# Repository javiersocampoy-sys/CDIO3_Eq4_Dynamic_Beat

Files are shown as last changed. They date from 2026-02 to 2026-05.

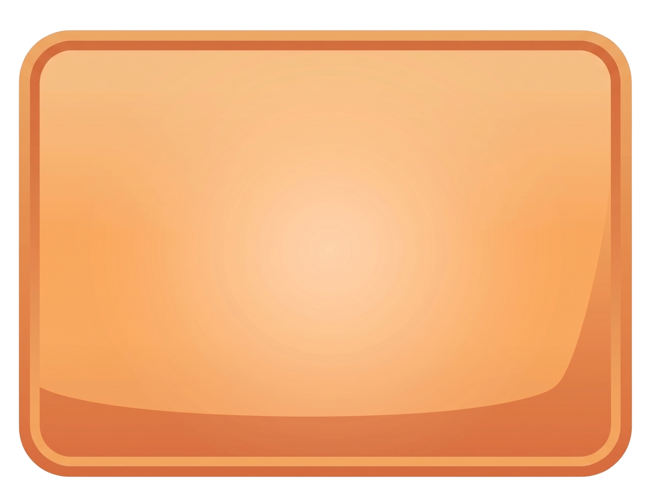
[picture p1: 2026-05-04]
03_Firmware/src/Codigo_Interfaz_Proyecto_CDIO/assets/CuadroInstrucciones.png

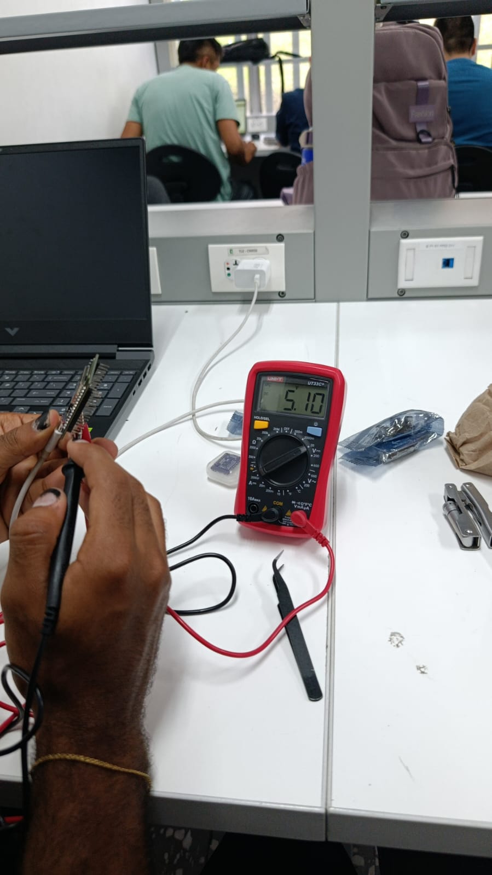
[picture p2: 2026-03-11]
04_Dossier/Evidencias/prueba alimentacion cORRIENTE Alterna.jpeg

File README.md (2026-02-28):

# CDIO3_Eq[4]_[Dynamic Beat]
En este repositorio se tendrá toda la documentación con respecto al proyecto correspondiente a la asignatura de CDIO3. 

Proyecto_CDIOIII_DYNAMIC_BEAT
DYNAMIC BEAT: Sistema interactivo para terapias de rehabilitación

DYNAMIC BEAT es una plataforma de rehabilitación basada en sistemas embebidos que digitaliza la terapia física mediante el juego. El sistema utiliza una arquitectura distribuida de sensores de ultrasonido para capturar la cinemática del paciente en tiempo real, proporcionando una métrica objetiva del progreso y transformando ejercicios repetitivos en desafíos dinámicos que aumentan la adherencia al tratamiento.

Objetivo del Proyecto
Desarrollar un prototipo didáctico de bajo costo para la Fundación Covida, enfocado en pacientes con movilidad reducida para medir y mejorar:

Precisión del Movimiento: Validación de la ejecución correcta de ejercicios mediante detección de proximidad.

Tiempo de Reacción: Medición de la velocidad de respuesta ante estímulos visuales/auditivos.

Engagement del Paciente: Gamificación de la terapia mediante una interfaz gráfica interactiva.

Seguimiento Clínico: Generación de registros de cada sesión para el análisis del terapeuta.

🛠️ Hardware y Arquitectura
El sistema opera bajo una arquitectura Hub-and-Spoke (Nodo Central y Periféricos) utilizando el protocolo ESP-NOW para una comunicación de baja latencia sin necesidad de infraestructura WiFi externa.

Lista de Componentes (BOM)

MCU Central: ESP32 WROOM 32 (Gestión de lógica y comunicación PC).

MCU Nodos (x4): XIAO ESP32C3 / Super Mini (Sensores inalámbricos remotos).

Sensores: HC-SR04 (Ultrasonido para interacción sin contacto).

Interfaz Visual: Interfaz gráfica desarrollada en Python (Pygame).

Energía: Baterías Li-ion 3.7V (2500mAh) + Regulador LM2596 + BMS para protección.

Diagrama de Bloques
[Nodos HC-SR04] --(ESP-NOW)--> [Hub ESP32] --(Serial/USB)--> [PC / Interfaz Python]

Funcionalidades Clave
1. Interacción Sin Contacto
A diferencia de los pulsadores físicos que pueden ser difíciles de accionar para pacientes con movilidad limitada, Dynamic Beat utiliza filtros de promedio móvil en los sensores ultrasonido para detectar gestos en el aire, facilitando la terapia.

2. Red Inalámbrica Propietaria
Implementa ESP-NOW, lo que permite que los objetivos de entrenamiento (nodos) se ubiquen en cualquier lugar de la sala de terapias sin cables estorbosos, manteniendo una sincronización de milisegundos con el software central.

Instalación y Uso
Firmware (ESP32/C3)

Clonar el repositorio de la lógica de sensores.

Abrir con Arduino IDE o Python.

Instalar librerías: WiFi.h, esp_now.h, NewPing (para HC-SR04).

Cargar el código de Master en el ESP32 WROOM y Slave en los nodos C3.

Software de Interfaz (PC)

Instalar Python.

Ejecutar pip install pygame pyserial.

Conectar el Hub USB y lanzar juegocdio.py.

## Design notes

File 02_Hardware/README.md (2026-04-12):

Hardware: Sistema de Rehabilitación 

Este apartado contiene toda la documentación técnica, diseños físicos y esquemáticos del hardware que compone el sistema de fisioterapia interactiva.

Descripción General

El hardware está diseñado como una red inalámbrica de sensores compuesta por 5 estaciones independientes (cajas) que funcionan bajo una arquitectura Maestro-Esclavo mediante el protocolo ESP-NOW:

Nodos Periféricos (4 estaciones): Cada caja actúa como un punto de interacción. Utilizan microcontroladores ESP32-C3 (versiones Supermini y con pantalla OLED integrada) conectados a sensores de ultrasonido HC-SR04 para detectar la proximidad de la extremidad del paciente.

Nodo Central (Maestro): Una unidad basada en ESP32 Wroom que centraliza la información de los periféricos y la transmite vía serial a un computador para la ejecución de la terapia (videojuego).

Gestión de Energía: Cada unidad es autónoma, alimentada por dos celdas de 3.7V en serie, reguladas mediante un módulo LM2596 para garantizar un voltaje estable de operación para los sensores y microcontroladores.

Contenido de la Carpeta

En esta rama del repositorio encontrarás la siguiente organización:

DATASHEETS

Contiene las hojas de especificaciones técnicas en formato PDF de los componentes críticos utilizados, asegurando que se conozcan los límites de operación de:
ESP32-C3 (Supermini & OLED version).
ESP32 Wroom.
Sensor HC-SR04.
Regulador LM2596.

MECHANICAL

Incluye los archivos de diseño para la fabricación de las 5 cajas del prototipo:

SOURCE

Contiene los archivos fuente originales y editables del diseño electrónico:

Esquemáticos de conexión.

Diseño de PCBs (en formatos compatibles con KiCad, Altium o Eagle según corresponda).

 Diagrama de Arquitectura - Dynamic Beat

A continuación, se presenta el diagrama detallado del sistema, mostrando el flujo de potencia (basado en la evidencia de cableado realizada) y la comunicación de datos:

```mermaid
graph TD
    %% Nivel 1: Energía
    subgraph Alimentacion [1. Suministro de Energía]
        BAT[2x Baterías 3.7V] -- "7.4V" --> REG[Regulador LM2596]
        REG -- "5V" --> MCU_P[ESP32-C3 Supermini]
    end

    %% Nivel 2: Acción/Sensores
    subgraph Perifericos [2. Estaciones de Interacción]
        MCU_P -- "Pines Digitales" --> HC[Sensor Ultrasonido HC-SR04]
    end

    %% Nivel 3: Comunicación Inalámbrica
    subgraph Wireless [3. Transporte de Datos]
        MCU_P -. "Protocolo ESP-NOW" .-> MASTER[Nodo Maestro: ESP32 Wroom]
    end

    %% Nivel 4: Procesamiento Final
    subgraph Interfaz [4. Salida al Videojuego]
        MASTER -- "Cable USB" --> PC[Computador: Dynamic Beat]
    end

    %% Estilos básicos
    style Alimentacion fill:#fdf,stroke:#333
    style Interfaz fill:#ddf,stroke:#333

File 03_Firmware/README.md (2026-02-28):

 Firmware Dynamic Beat 
 
Este repositorio contiene el código fuente en C++ para el sistema de control del dispositivo de fisioterapia. El firmware gestiona la lectura de sensores ultrasónicos, el control de actuadores y la interfaz de usuario, operando bajo una arquitectura de Máquina de Estados Finitos (FSM) para garantizar la precisión en las rutinas de terapia.

 Entorno de Desarrollo
Platform: PlatformIO (Recomendado) o Arduino IDE.

Framework: Arduino.

Board: esp32-c3-devkitm-1 / esp32dev (Ajustar según el módulo específico usado, como el C3 Supermini o Wroom).

Dependencias (Librerías)
Para compilar este proyecto, es necesario instalar las siguientes librerías:

NewPing (Optimización de sensores HC-SR04).

Adafruit SSD1306 (Controlador de la pantalla OLED).

Adafruit GFX (Gráficos para la interfaz).

WiFi.h (Gestión de conectividad si se usa el Wroom para telemetría).

 Pinout (Mapa de Conexiones - Borrador)
Configuración de pines sugerida (puedes ajustarla según tu config.h real):

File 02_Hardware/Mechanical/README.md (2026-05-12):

# Diseño Mecánico y Ensamblaje

Esta carpeta contiene los planos y archivos necesarios para la fabricación de la estructura física y electrónica del proyecto Dynamic Beat. 

A continuación se detalla el contenido:

* **Modelos_3D/**: Contiene los archivos 3D para imprimir las carcasas. Aquí se encuentran los diseños para las 4 cajas iguales de los nodos periféricos y el diseño específico para la caja del nodo principal (maestro).
* **Archivos_PCB/**: Contiene los documentos finales para la fabricación de las placas de circuito. Incluye los archivos técnicos Gerber (comprimidos en .zip) y los planos en PDF que muestran el diseño del circuito esquemático y el recorrido de las pistas de cobre.
* **esquematico_conexion_esp-ultrasonido**: Diagrama detallado que muestra la disposición física del sensor de ultrasonido HC-SR04 respecto a la estructura de la caja, para asegurar una detección óptima de la extremidad del paciente.

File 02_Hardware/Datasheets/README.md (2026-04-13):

Hojas de Datos (Datasheets)

En esta sección se centraliza la documentación técnica de los componentes electrónicos utilizados en el prototipo.

BOM_Sourcing.pdf: Listado de materiales (Bill of Materials) detallando proveedores, cantidades y costos aproximados para la replicación del hardware.

Documentación de Componentes: Información técnica del ESP32-C3,Placa OLED ESP32-C3 con módulo OLED, ESP32-Wroom, sensor HC-SR04 y el regulador LM2596, necesaria para entender los rangos de voltaje y operación del sistema.

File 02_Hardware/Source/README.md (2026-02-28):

Archivos Fuente Electrónicos

Aquí se encuentran los archivos originales de diseño de circuitos y esquemáticos eléctricos del sistema.

esquematico conexion fuente: Diagrama del sistema de alimentación. Detalla la conexión de las dos pilas de 3.7V en serie hacia el regulador LM2596 y la distribución de potencia a los módulos ESP32.

Diseño de Circuito: Archivos editables (KiCad/Altium/Eagle) con el ruteado de pistas y conexiones entre los nodos esclavos y el nodo maestro.

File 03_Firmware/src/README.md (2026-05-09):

#  Códigos del Sistema

Esta carpeta contiene todo el código fuente necesario para el funcionamiento de la red de sensores y la visualización de datos. La arquitectura del software está dividida en tres componentes principales: el firmware para los nodos de adquisición, el firmware del nodo central y el software de escritorio.

##  Estructura del Directorio

*   **`EMISORES`**: Contiene el firmware desarrollado para los microcontroladores ESP32 que actúan como nodos periféricos. Estos dispositivos se encargan de la lectura de los sensores (como los sensores ultrasónicos) y de transmitir la información de forma inalámbrica hacia el nodo central, utilizando el protocolo de comunicación ESP-NOW para garantizar una baja latencia.
*   **`RECEPTOR`**: Contiene el firmware para el ESP32 que actúa como nodo central o *gateway*. Este dispositivo recibe los paquetes de datos de todos los emisores de la red a través de ESP-NOW y los retransmite hacia la computadora mediante comunicación serial.
*   **`Codigo_Interfaz_Proyecto_CDIO`**: Contiene los scripts en Python que conforman la interfaz gráfica y el sistema de procesamiento. Esta aplicación lee los datos del puerto serie, los procesa y proporciona retroalimentación visual en tiempo real. 

## ⚙️ Notas de Implementación

1.  **Firmware (ESP32):** Antes de cargar los códigos, asegúrate de configurar correctamente las direcciones MAC en los archivos para que la red ESP-NOW entre los emisores y el receptor se establezca exitosamente.
2.  **Software (Python):** Verifica tener instaladas las dependencias necesarias (`pygame`, `pyserial`, etc.) antes de ejecutar el script principal de la interfaz. Puedes instalarlas ejecutando `pip install -r requirements.txt` (si aplica).

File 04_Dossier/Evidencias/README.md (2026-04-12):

Evidencias del Proyecto
Este directorio centraliza toda la documentación de respaldo, registros de validación y material gráfico recopilado durante las distintas fases de desarrollo y ensamble del sistema Dynamic Beat.

El propósito de esta carpeta es garantizar la trazabilidad de los resultados físicos y matemáticos obtenidos antes y durante la integración final.

Contenido del Directorio
La información en esta carpeta se pueden encontrar organizadas las siguientes categorías principales:

Protocolos de Pruebas: Contiene las plantillas de validación y los resultados de los puntos de prueba físicos. Esto incluye las mediciones de consumo de baterías, la verificación de los tiempos de respuesta de los sensores ultrasónicos y los reportes de estabilidad en la transmisión de datos concurrente mediante ESP-NOW.

Registros de Hardware y Control: Almacena la evidencia de la caracterización de los sistemas y el acondicionamiento de señales. Se incluyen las gráficas de respuesta en frecuencia, datos de adquisición de MATLAB/Simulink y las pruebas de velocidad del motor DC validadas con tacómetro físico.

Construcción y Ensamblaje: Archivos multimedia (fotografías y videos) que documentan el progreso físico del hardware. Abarca desde el proceso de manufactura de las PCB en la CNC y la regulación de potencia, hasta el modelado 3D y el acople del chasis electromecánico.

Sustentación y Contexto Social: Material de apoyo utilizado en las entregas formales del proyecto CDIO. Incluye los documentos y presentaciones relacionadas con el impacto del proyecto, como los soportes de la exposición sobre ingeniería electrónica, inclusión social y tecnología de asistencia.

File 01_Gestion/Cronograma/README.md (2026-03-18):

#  CDIO3_Eq4_Dynamic_Beat - Dispositivo de Fisioterapia

Este repositorio contiene el código fuente, el diseño de hardware y la documentación técnica correspondiente al desarrollo del Prototipo Mínimo Viable (PMV) de nuestro dispositivo de asistencia fisioterapéutica.

## 📑 Tabla de Contenidos
- [Tecnologías Utilizadas](#-tecnologías-utilizadas)
- [Estado del Proyecto](#-estado-del-proyecto-pmv)
- [Cronograma de Ejecución](#-cronograma-de-ejecución)

## 🛠️ Tecnologías Utilizadas
- **Microcontroladores:** Red de placas ESP32
- **Sensores:** Arreglo de sensores ultrasónicos
- **Diseño de Hardware:** Desarrollo de PCB a medida y modelado de carcasa 3D
- **Validación:** Pruebas de software e interfaz de usuario

## ⚠️ Estado del Proyecto (PMV)
Actualmente contamos con un prototipo base funcional y los siguientes entregables en curso:
- **Gestión:** Lista de materiales (BOM) consolidada y elementos adquiridos.
- **Hardware:** Diseño de circuito base completado; en fase de pruebas físicas.
- **Software:** Pruebas iniciales de software e interfaz superadas.

## 📅 Cronograma de Ejecución

A continuación, se presenta la planificación del proyecto distribuida por semanas académicas y fases de desarrollo:

```mermaid id="x8m4qp"
gantt
    title Plan de Proyecto Dynamic Beat - Semestre 2026-I
    dateFormat YYYY-MM-DD
    axisFormat %d/%m

    section Fase 1 - Diseño y Prototipado
    Lista de Materiales BOM :done, des1, 2026-02-09, 7d
    Adquisición de Componentes :done, des2, after des1, 7d
    Diseño de Circuito Electrónico :done, des3, 2026-02-16, 14d
    Pruebas de Software e Interfaz :done, des4, 2026-02-23, 14d
    Prototipo Base Terminado :milestone, 2026-03-09, 1d

    section Fase 2 - Hardware
    Validación Física Sem 6 y 7 :active, dev1, 2026-03-09, 14d
    Diseño PCB Definitiva Sem 8 :dev2, after dev1, 7d
    Modelado Carcasa 3D Sem 9 :dev3, after dev2, 7d

    section Fase 3 - Integración
    Ensamble y Pruebas Sem 10 :int1, after dev3, 7d
    Validación Operativa Sem 11 :int2, after int1, 7d

    section Fase 4 - Implementación
    Evaluación con Cliente Sem 12 :crit, usr1, after int2, 21d
    Ajustes de Mejora Continua :doc1, after usr1, 7d
    Sustentación Final Sem 15 :milestone, 2026-05-11, 1d
```

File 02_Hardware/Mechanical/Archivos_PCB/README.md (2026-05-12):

# Archivos de la PCB

En esta carpeta se guardan todos los documentos finales para la fabricación y revisión de las placas de circuito del proyecto Dynamic Beat. Aquí encontrarás:

- **Archivos Gerber (.zip):** Los archivos técnicos comprimidos listos para mandar a fabricar las placas (PCB) mediante CNC o con un fabricante.
- **Planos en PDF:** Documentos de fácil lectura que muestran el diseño del circuito (esquemático) y el diseño físico con las pistas (ruteo) de los nodos.

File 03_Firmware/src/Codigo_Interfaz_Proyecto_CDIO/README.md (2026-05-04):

Esta carpeta contiene el **código principal del sistema interactivo**, desarrollado en Python utilizando **Pygame**, el cual se comunica con un **ESP32** mediante puerto serial.
El juego está diseñado para ser utilizado en sesiones de fisioterapia, donde el usuario interactúa con sensores físicos que envían señales al sistema.

### 🔹 main.py

Contiene:

* Lógica completa del juego
* Lectura del puerto serial (ESP32)
* Renderizado de la interfaz gráfica
* Control de puntuación, animaciones y flujo del juego

### 🔹 assets/

Contiene todos los recursos gráficos utilizados:

* Imágenes (botones, fondos, flechas, personajes)
* Tipografías personalizadas (.ttf)

⚠️ IMPORTANTE:
El código actualmente usa una **ruta absoluta**, por lo que debe modificarse para que funcione en otros equipos.

Ejemplo actual:

```python
ruta_imagenes = "C:\\Users\\Javier S Ocampo\\Documents\\Juego CDIO\\Imagenes"
```

Se recomienda cambiarlo a ruta relativa:

```python
ruta_imagenes = os.path.join(os.path.dirname(__file__), "assets")
```

---

##  Requisitos para ejecutar el sistema

Antes de ejecutar el código, asegúrese de tener instalado:

* Python 3.x
* Librerías necesarias:

```bash
pip install pygame pyserial
```

---

##  Configuración del puerto serial (MUY IMPORTANTE)

El sistema se comunica con un **ESP32**, por lo tanto es necesario configurar correctamente el puerto serial.

###  Línea a modificar en el código:

```python
puerto_serial = serial.Serial('COM4', 115200, timeout=0.01)
```

###  ¿Qué debe hacer el usuario?

* En Windows:

  1. Abrir el **Administrador de dispositivos**
  2. Buscar el ESP32 en "Puertos (COM y LPT)"
  3. Identificar el puerto asignado (ej: COM3, COM5, etc.)
  4. Reemplazar `'COM4'` por el puerto correspondiente

* En Linux/Mac:
  Puede ser algo como:

  ```bash
  /dev/ttyUSB0
  /dev/ttyACM0
  ```

---

##  Cómo ejecutar el juego

1. Conectar el ESP32 al computador
2. Verificar el puerto serial
3. Ajustar la ruta de imágenes (si es necesario)
4. Ejecutar:

```bash
python main.py
```

---

##  Funcionamiento del sistema

El ESP32 envía datos por serial en el siguiente formato:

```
SensorX -> Letra
```

Ejemplo:

```
Sensor1 -> B
```

El sistema interpreta estas letras como direcciones:

| Letra | Acción |
| ----- | --- |
| B | Arriba (↑) |
| A | Abajo (↓) |
| C | Izquierda (←) |
| D | Derecha (→) |

---

## ⚠️ Consideraciones importantes

* Si el juego no responde:

  * Verificar conexión serial
  * Verificar puerto correcto
* Si no cargan imágenes:

  * Revisar rutas en `assets`
* Si hay errores:

  * Revisar instalación de librerías

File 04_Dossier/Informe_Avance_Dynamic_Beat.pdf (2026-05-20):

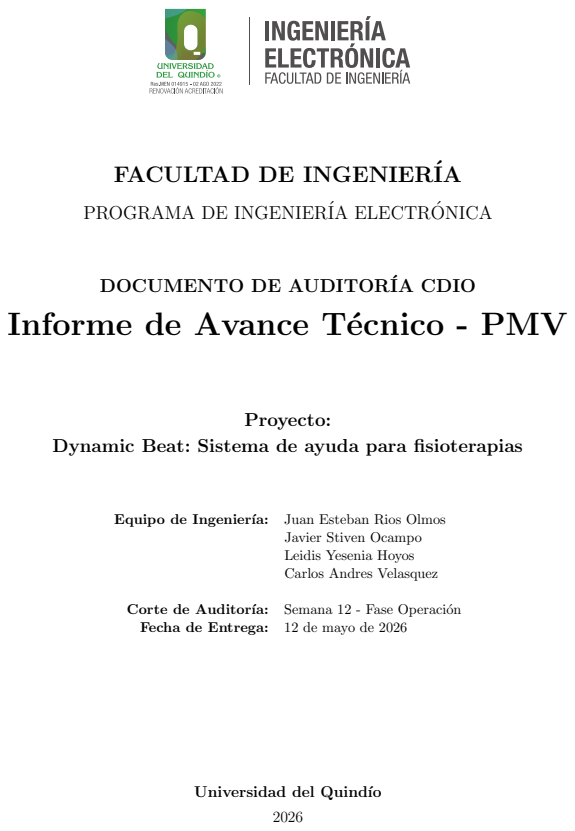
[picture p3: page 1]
Proyecto:; Equipo de Ingeniería:; Juan Esteban Rios Olmos; Corte de Auditoría:; Semana 12 - Fase Operación; Fecha de Entrega:; 12 de mayo de 2026

FACULTAD DE INGENIERÍA

PROGRAMA DE INGENIERÍA ELECTRONICA ´

DOCUMENTO DE AUDITORÍA CDIO

Informe de Avance Técnico - PMV

Dynamic Beat: Sistema de ayuda para fisioterapias

Javier Stiven Ocampo
Leidis Yesenia Hoyos
Carlos Andres Velasquez

Universidad del Quindío

## Índice

1. Resumen Ejecutivo | 2
2. Estado de Cumplimiento ON-Ramp | 2
3. Resultados de Verificación y Validación (V&V) | 2
4. Desempeño Operativo (MAHD + Kanban) | 3
5. Auditoría Financiera (CVU) | 3
6. Próximos Pasos (Roadmap S12 a S14) | 3
7. Anexos y Evidencia Técnica | 5

## 1. Resumen Ejecutivo

El proyecto Dynamic Beat se reporta actualmente en estado VERDE-AMARILLO. El logro principal (IPAC) de este ciclo fue la consolidación de la arquitectura de hardware, utilizando 1 ESP32-WROOM como receptor central de la información enviada por 4 módulos ESP32-C3 SuperMini mediante el protocolo ESP-NOW, integrándose exitosamente con la interfaz gráfica en Python. Se alcanzó la validación eléctrica completa, operando de manera autónoma con 2 baterías LiPo y un regulador LM2596 que entrega una salida estable de 5.06 V bajo carga. El estado de precaución se debe netamente a desafíos mecánicos superados recientemente durante el ensamble de las carcasas, garantizando un PMV auditable.

## 2. Estado de Cumplimiento ON-Ramp

A continuación, se contrasta la promesa técnica del diseño inicial frente a la realidad del prototipo funcional en la Semana 12.

Tabla 1: Trazabilidad de Requisitos: Matriz ON-Ramp vs. PMV Actual

ID | Requisito Original (Promesa) | Estado | Observaciones / Desviaciones
RF-001 | Entrada de 8.7V (±5 %). Salida 5V
(±0.3V).

Logrado Operación exitosa a 5.06 V constantes vía módulo Step-Down LM2596 alimentado por dos baterías LiPo.

RF-004 | Visualización | de | imágenes | sin
distorsión | (Resolución | mínima
| 800x700px).
Logrado | Interfaz de juego implementada en
Pygame a 800x700px.

RNF-001 Operar con variaciones de voltaje sin fallos (±10 %).

Logrado Sistema estable operando a baterías con autonomía de 3 a 5 horas continuas sin reinicios de los microcontroladores.

RNF-003 | Tiempo de respuesta en la selección
| menor a 1s.
Logrado | Antirrebote por software imple-
mentado exitosamente tras validar el uso de sensores HC-SR04 para detección de extremidades.

RNF-005 Protección IP40 contra polvo y humedad (± 1 nivel).

Logrado Las carcasas encajan con las tapas y son celladas con tornillos, protegiendo efectivamente las PCBs del polvo, garantizando protección de nivel básico.

## 3. Resultados de Verificación y Validación (V&V)

El proceso de V&V se ha ejecutado conforme al protocolo establecido en el laboratorio. Las 9 pruebas documentadas en el registro oficial culminaron en estado PASS, incluyendo validaciones críticas de comunicación y detección de extremidades en los nodos.
Durante el desarrollo de la interfaz gráfica y los sensores (reemplazando los botones físicos originales por ultrasonido HC-SR04 para mejorar la accesibilidad), se detectaron y solucionaron dos fallos lógicos. El primero fue un rebote de señal donde una sola interacción generaba múltiples aciertos y fallos simultáneos, lo cual se mitigó programando un cooldown (antirrebote) en el código. El segundo fallo fue un error de mapeo en la transmisión serial que causaba que la interfaz solo detectara el nodo amarillo e ignorara el resto de colores, lo cual fue solucionado sincronizando la lectura de línea completa para extraer únicamente el identificador correcto de cada ESP Mini.

Tabla 2: Consolidado de Pruebas Técnicas Ejecutadas (Muestra representativa)

ID Prueba | Parámetro Evaluado | Resultado | Dato Registrado (Eviden-
cia)
TEST-HW-01 | Regulación | de | voltaje
(LM2596).

PASS Salida estable 4.9 V - 5.1 V bajo carga de 10Ω.

TEST-PWR-02 | Consumo y batería. | PASS | Autonomía operativa continua
de 3 a 5 horas.
TEST-COM-03 | Transmisión Serial PC-ESP. | PASS | Datos íntegros tras lag inicial
de emparejamiento.
TEST-SEN-01 | Detección ultrasónica. | PASS | Detección de extremidades con
margen de error mínimo.

## 4. Desempeño Operativo (MAHD + Kanban)

### 4.1. Gestión de Flujo y Cuellos de Botella

La fase de manufactura física representó el mayor cuello de botella. Se identificaron tres percances mecánicos: 1) Los cables de los portapilas comerciales sufrieron fatiga mecánica debido al peso de las baterías, rompiéndose repetidamente, lo que obligó a reemplazarlos por cableado de mayor calibre. 2) La primera iteración de la PCB fresada (TEST-HW-03) falló por la omisión del efecto espejo en los footprints, retrasando el ensamble por 2 días hasta la manufactura de la placa corregida. 3) Se requirió un re-diseño operativo en la carcasa para incluir un switch externo, evitando destapar los módulos para el encendido.

### 4.2. Estado del Repositorio (GitHub)

La trazabilidad del proyecto refleja un alto nivel de actividad. A la fecha, se han registrado

### 89 commits en la red del repositorio. El tablero Kanban evidencia 13 tareas finalizadas

(Done) y 5 tareas activas (In Progress) centradas principalmente en validación (Validation) y desarrollo (Development).

## 5. Auditoría Financiera (CVU)

El Costo Variable Unitario (CVU) ejecutado se basa en el Bill of Materials (BOM) actualizado. Dado que no se fijó un presupuesto inicial rígido, se reporta la liquidación neta actual para la trazabilidad de los activos. (El desglose detallado de los componentes se presenta al final de este informe en la Tabla 3).

## 6. Próximos Pasos (Roadmap S12 a S14)

El Backlog para el cierre técnico del hardware queda sujeto a las iteraciones y modificaciones que la dirección académica (profesor) exija tras esta auditoría. Las tareas preliminares incluyen la estabilización final de la interfaz de juego y la actualización de los repositorios en GitHub con las versiones As-Built de los esquemáticos y la documentación.

Tabla 3: Análisis de Costos de Hardware (BOM Real Ejecutado)

Componente | Cant. | V. Unitario | Costo Total
ESP32 C3 SuperMini | 2 | $ 9,348.00 | $ 18,696.00
Placa OLED ESP32-C3 | 2 | $ 10,814.44 | $ 21,628.88
ESP32 Wroom 32 | 1 | $ 14,481.95 | $ 14,481.95
Sensor HC-SR04 | 4 | $ 12,000.00 | $ 48,000.00
Batería LiPo 3.7V | 8 | $ 12,000.00 | $ 96,000.00
Portapilas para baterías LiPo | 4 | $ 4,000.00 | $ 16,000.00
Cargador de baterías | 1 | $ 14,000.00 | $ 14,000.00
Regulador LM2596 | 1 | $ 14,000.00 | $ 14,000.00
Cajas | 5 | $ 7,400.00 | $ 37,000.00
PCB impresa | 2 | $ 2,400.00 | $ 4,800.00
Borneras de alimentación | 4 | $ 800.00 | $ 3,200.00
Regletas de pines | 3 | $ 2,000.00 | $ 6,000.00
Cable USB-C (Microcontrolador Maestro) | 1 | $ 20,000.00 | $ 20,000.00
LED RGB indicador | 1 | $ 1,000.00 | $ 1,000.00
Resistencias de 100 y 39 Ohms | 3 | $ 200.00 | $ 600.00
Soldadura (Estaño 1 metro) | 1 | $ 2,000.00 | $ 2,000.00
Switch externo | 4 | $ 800.00 | $ 3,200.00
Decoración | 1 | $ 2,000.00 | $ 2,000.00
TOTALES | 47 | $ 129,244.39 | $ 322,606.83

## 7. Anexos y Evidencia Técnica

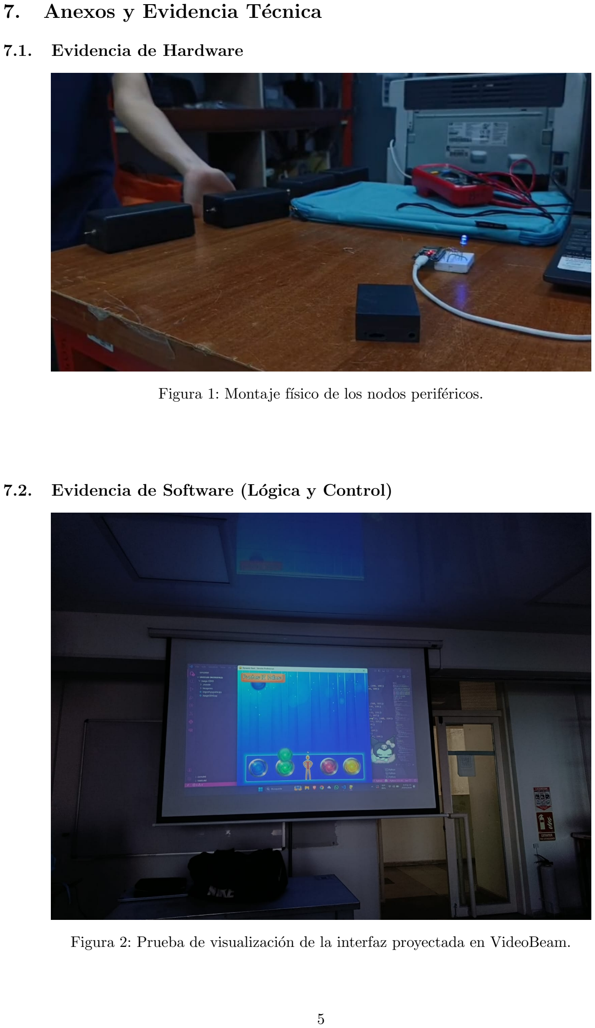
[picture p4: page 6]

### 7.1. Evidencia de Hardware

Figura 1: Montaje físico de los nodos periféricos.

### 7.2. Evidencia de Software (Lógica y Control)

Figura 2: Prueba de visualización de la interfaz proyectada en VideoBeam.

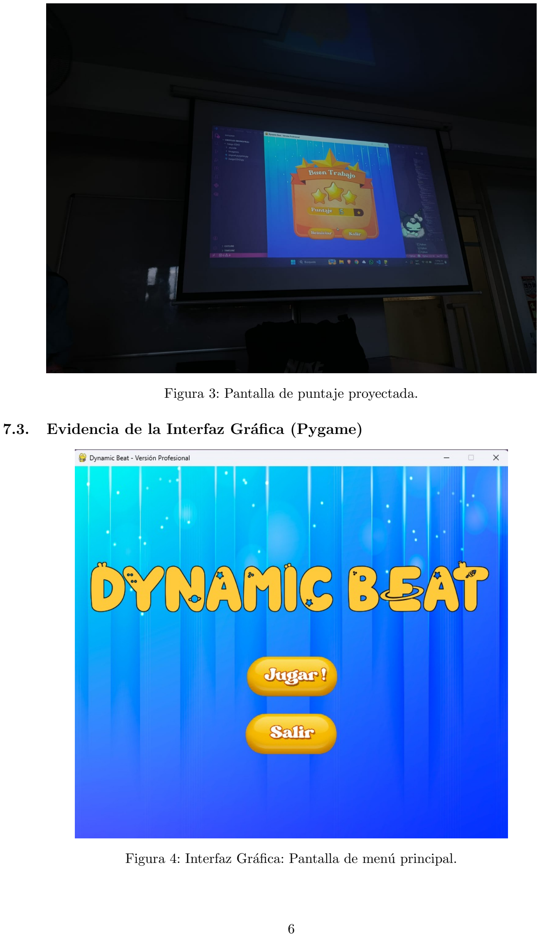
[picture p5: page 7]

Figura 3: Pantalla de puntaje proyectada.

### 7.3. Evidencia de la Interfaz Gráfica (Pygame)

Figura 4: Interfaz Gráfica: Pantalla de menú principal.

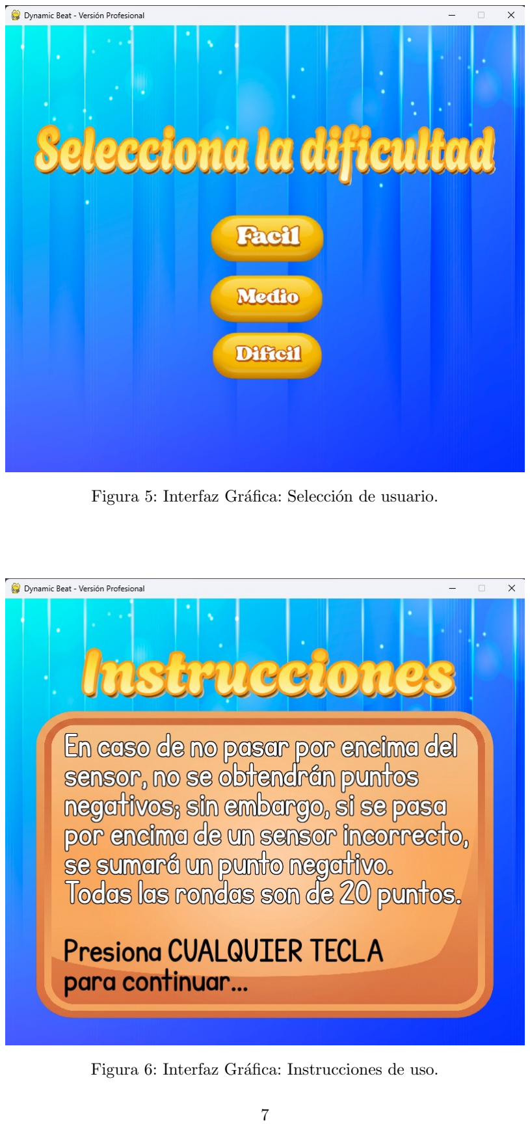
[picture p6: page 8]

Figura 5: Interfaz Gráfica: Selección de usuario.

Figura 6: Interfaz Gráfica: Instrucciones de uso.

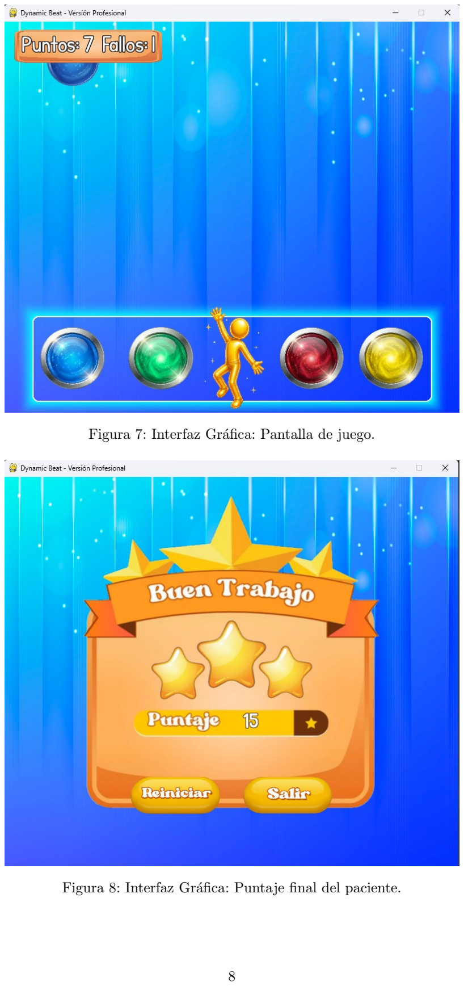
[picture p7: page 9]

Figura 7: Interfaz Gráfica: Pantalla de juego.

Figura 8: Interfaz Gráfica: Puntaje final del paciente.

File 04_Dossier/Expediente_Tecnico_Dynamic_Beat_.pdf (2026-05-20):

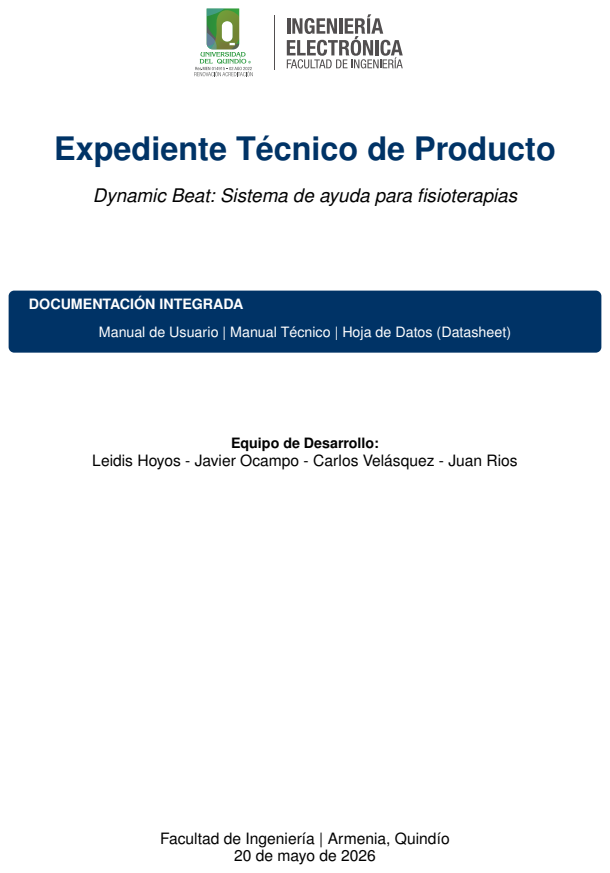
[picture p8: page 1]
DOCUMENTACIÓN INTEGRADA

Expediente Técnico de Producto

Dynamic Beat: Sistema de ayuda para fisioterapias

Manual de Usuario | Manual Técnico | Hoja de Datos (Datasheet)

Equipo de Desarrollo:

Leidis Hoyos - Javier Ocampo - Carlos Velásquez - Juan Rios

Facultad de Ingeniería | Armenia, Quindío

20 de mayo de 2026

Proyecto CDIO III: DYNAMIC BEAT | Rev. 1.2 - Mayo 2026

## Índice

1. HOJA DE DATOS (DATASHEET) | 2
2. MANUAL DE USUARIO | 6
3. MANUAL TÉCNICO | 11
Universidad del Quindío - Ingeniería Electrónica | 1

## 1 HOJA DE DATOS (DATASHEET)

### 1.1 Descripción General

DYNAMIC BEAT es un sistema inalámbrico de asistencia para rehabilitación motriz compuesto por un nodo maestro (ESP32-WROOM32) y cuatro nodos periféricos (2 ESP32-C3 SuperMini y 2 ESP32-C3 SuperMini OLED). El sistema utiliza sensores ultrasónicos (ver Figura 4) para la detección de presencia sin contacto, facilitando terapias de bajo impacto físico. La comunicación se realiza mediante el protocolo ESP-NOW, garantizando latencias inferiores a 400ms.

### 1.2 Especificaciones Técnicas

Parámetro | Descripción | Valor/Unidad
Voltaje de Alimentación Nominal | Entrada DC regulada (LiPo 2S) | 7,4V − 8,4V
Consumo Nominal | Corriente promedio del sistema | 300mA
Autonomía de Batería | Tiempo de operación continua | 3,0 − 5,0 h
Rango de Detección | Distancia útil del sensor HC-SR04 | 3,0 − 15,0 cm
Precisión de Medición | Margen de error en distancia | ±3,0 mm
Ángulo de Detección | Cono de medición efectivo | < 15◦
Latencia de Sistema | Tiempo de respuesta End-to-End | 0,34 s
Frecuencia de Operación | Banda ISM Inalámbrica | 2,4 GHz

Tabla 1: Especificaciones operativas nominales del sistema.

### 1.3 Valores Máximos Absolutos

Nota: Operar el dispositivo bajo estas condiciones por periodos prolongados puede afectar la fiabilidad del equipo o causar daño permanente a los microcontroladores.

Parámetro | Condición | Límite Máximo
Voltaje de Entrada (Etapa Regulación) | Directo a la placa de distribución | 8,6V DC
Voltaje Máximo Transitorio (ESP32) | Picos de corta duración en la ló-gica | 5,6V DC
Temperatura de Operación | Ambiente de trabajo (Carcasas PLA) | ◦C a 45◦C 0
Temperatura de Almacenamiento | Equipo apagado y guardado | −10◦C a 50◦C

Tabla 2: Límites máximos de tolerancia de hardware.

### 1.4 Características Mecánicas

Los nodos están protegidos por carcasas fabricadas mediante manufactura aditiva en material PLA, diseñadas para soportar el impacto moderado del uso fisioterapéutico.

### 1.5 Diagramas de Conexiones y Hardware

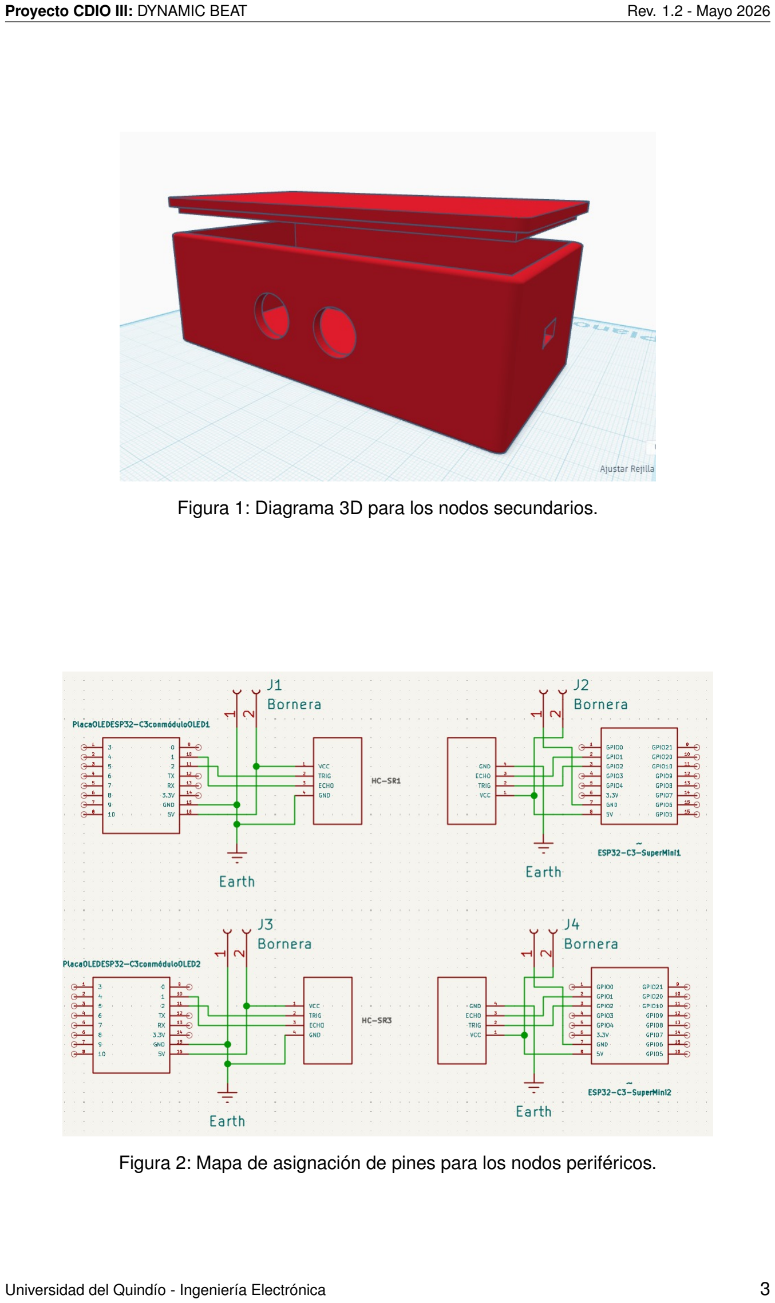
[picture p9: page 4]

Figura 1: Diagrama 3D para los nodos secundarios.

Figura 2: Mapa de asignación de pines para los nodos periféricos.

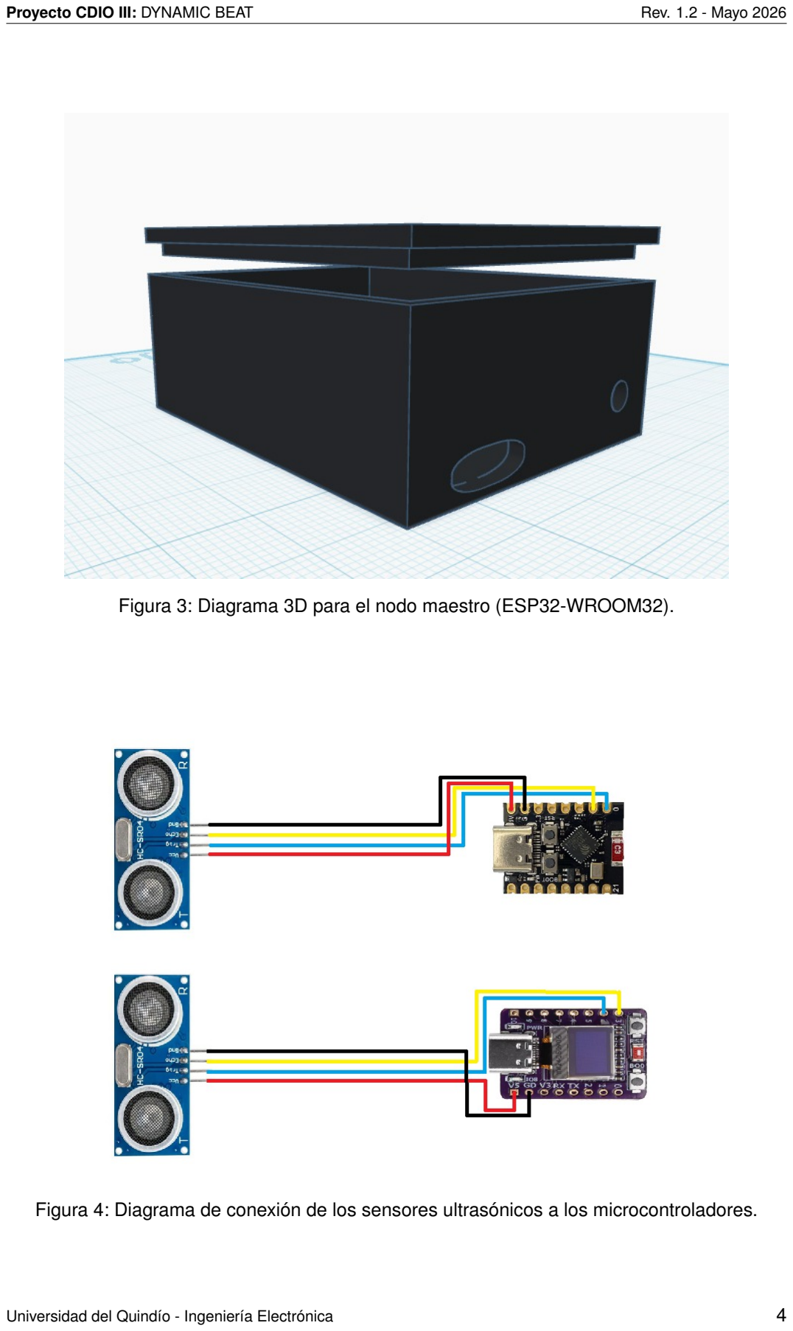
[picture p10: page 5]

Figura 3: Diagrama 3D para el nodo maestro (ESP32-WROOM32).

Figura 4: Diagrama de conexión de los sensores ultrasónicos a los microcontroladores.

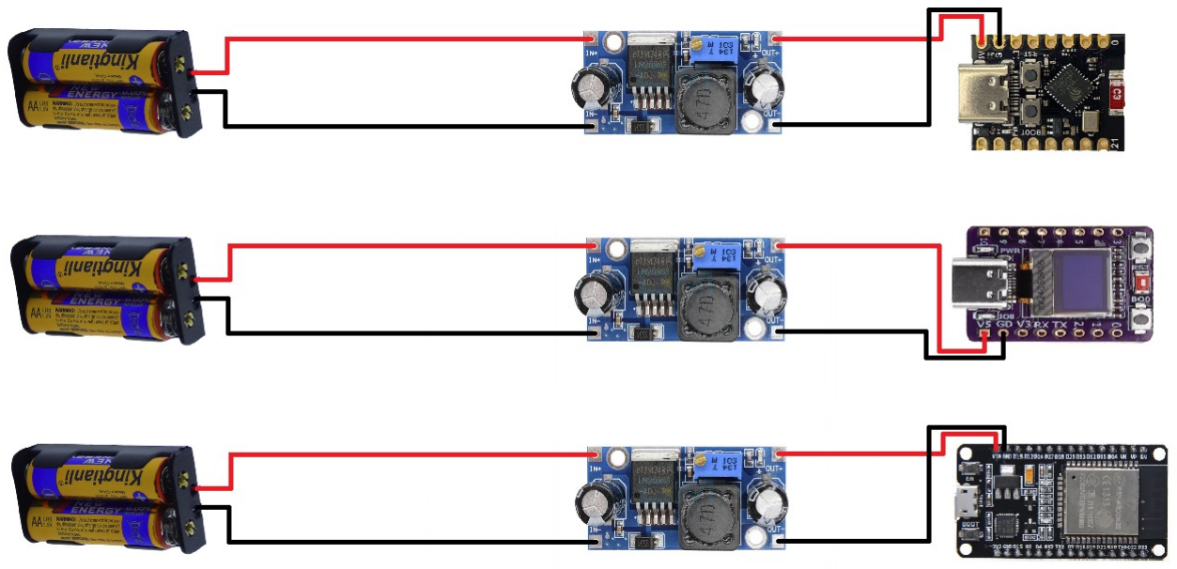
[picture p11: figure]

Figura 5: Diagrama de conexión de las baterías, reguladores y microcontroladores.

## 2 MANUAL DE USUARIO

. ADVERTENCIA DE SEGURIDAD

No exponga las carcasas a humedad directa. En caso de detectar olor a quemado o sobrecalentamiento, mueva todos los interruptores a la posición OFF de inmediato.

### 2.1 Contenido del Paquete

El sistema DYNAMIC BEAT incluye los siguientes elementos. Por favor, verifique que todos estén presentes antes de iniciar:

1x Nodo principal: Carcasa pequeña con LED indicador y entrada USB tipo C.

4x Nodos sensoriales: Carcasas con identificadores de colores.

1x Cable USB-C: Para alimentación y comunicación del nodo principal.

1x Cargador de baterías: Para la recarga de las baterías 18650 de los nodos.

1x Software: Aplicación de interfaz gráfica Dynamic Beat.

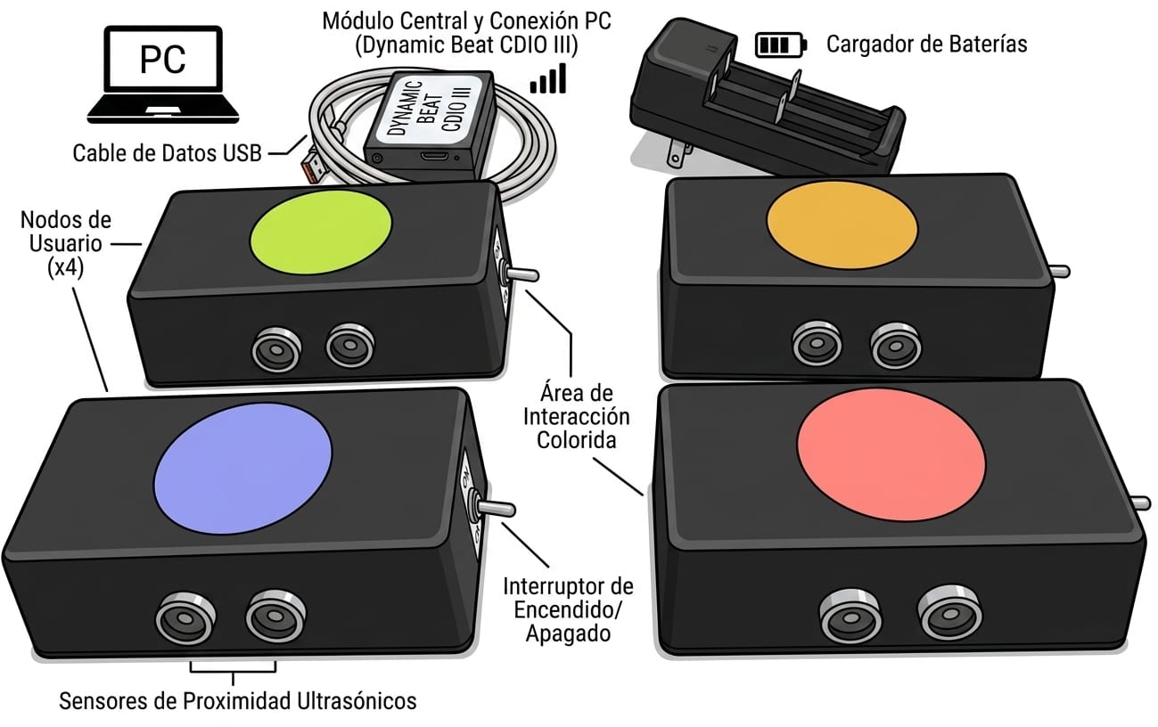
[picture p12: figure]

Figura 6: Materiales entregados y disposición de los componentes del sistema.

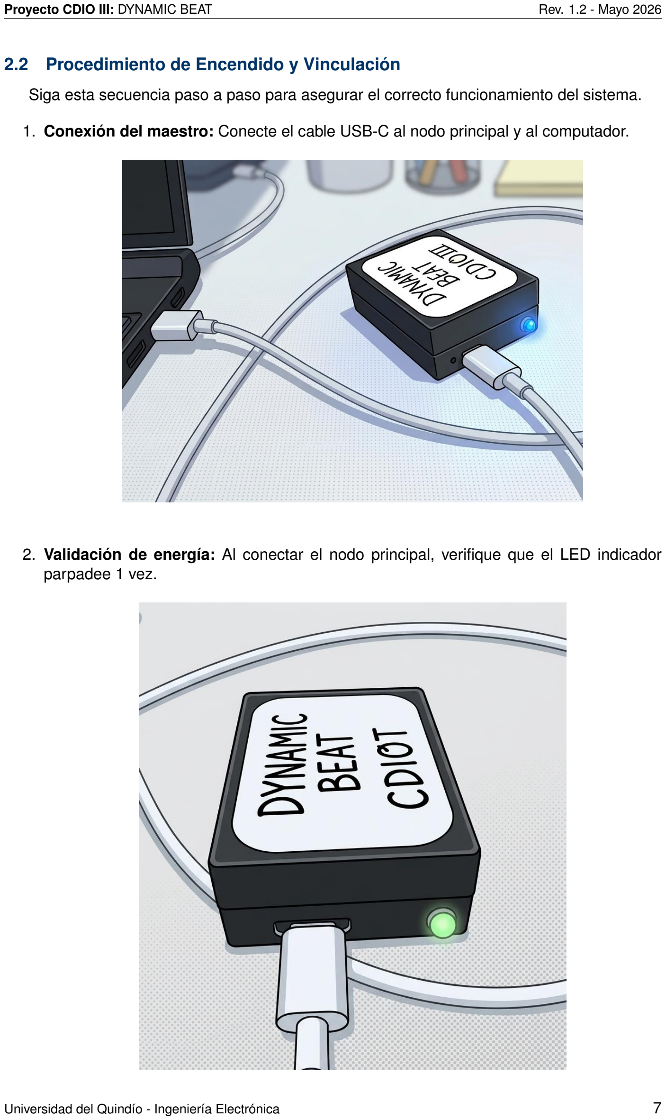
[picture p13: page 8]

### 2.2 Procedimiento de Encendido y Vinculación

Siga esta secuencia paso a paso para asegurar el correcto funcionamiento del sistema.

1. Conexión del maestro: Conecte el cable USB-C al nodo principal y al computador.
2. Validación de energía: Al conectar el nodo principal, verifique que el LED indicador parpadee 1 vez.

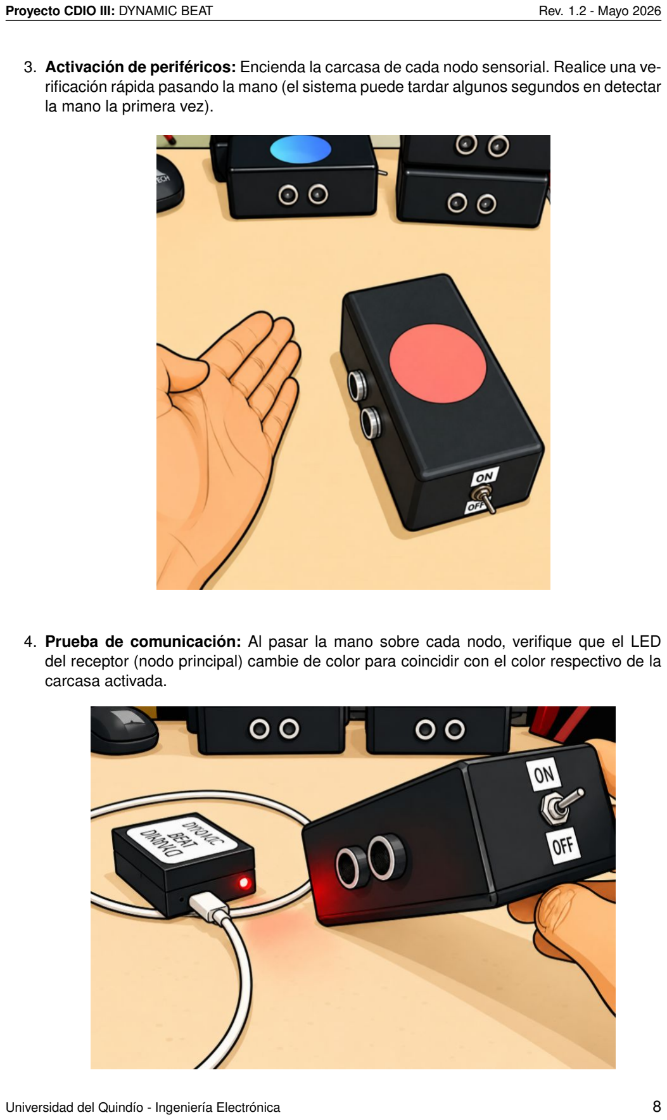
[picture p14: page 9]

3. Activación de periféricos: Encienda la carcasa de cada nodo sensorial. Realice una verificación rápida pasando la mano (el sistema puede tardar algunos segundos en detectar la mano la primera vez).
4. Prueba de comunicación: Al pasar la mano sobre cada nodo, verifique que el LED del receptor (nodo principal) cambie de color para coincidir con el color respectivo de la carcasa activada.

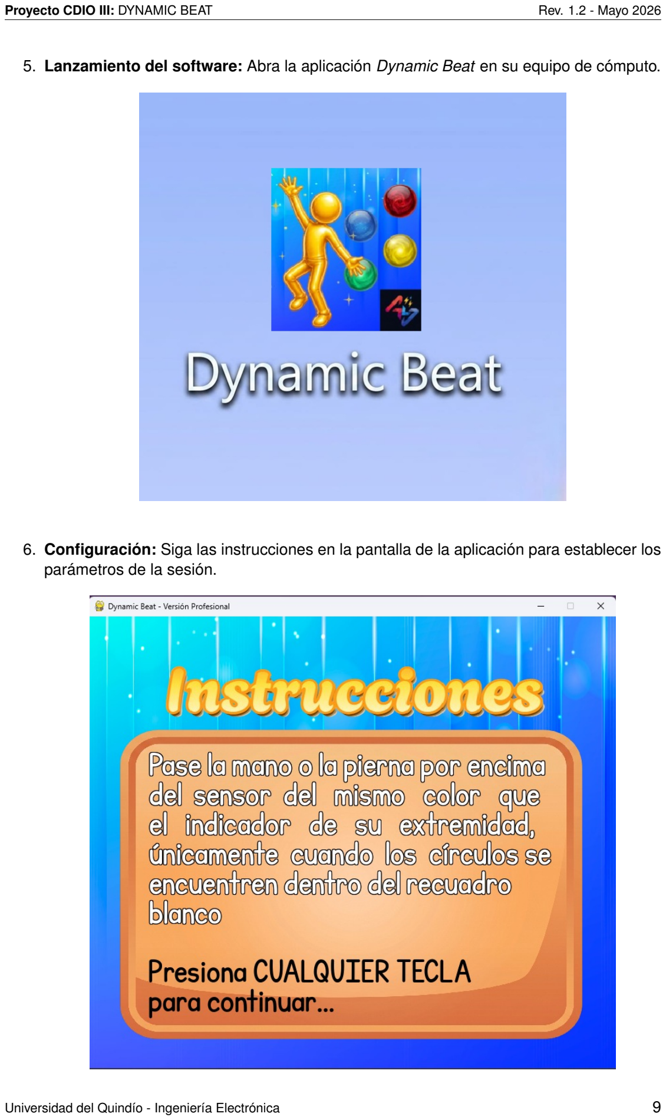
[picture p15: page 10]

5. Lanzamiento del software: Abra la aplicación Dynamic Beat en su equipo de cómputo.
6. Configuración: Siga las instrucciones en la pantalla de la aplicación para establecer los parámetros de la sesión.

7. ¡Iniciar prueba!: Una vez configurado todo en el software, inicie la rutina e interactúe con los nodos.

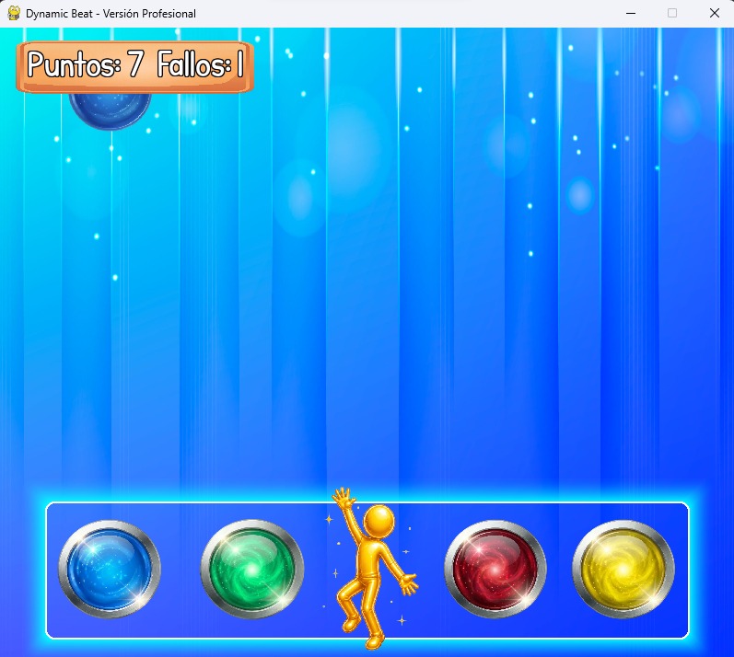
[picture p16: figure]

### 2.3 Tabla de Diagnóstico y Solución de Problemas

Si el sistema presenta alguna falla en su funcionamiento, localice el síntoma en la siguiente tabla y siga las instrucciones recomendadas antes de solicitar asistencia técnica.

Síntoma / Problema | Posible Causa | Solución Sugerida
El nodo sensorial no en-ciende o la luz indicadora se apaga de forma inter-mitente. | Las baterías 18650 están to-talmente descargadas o se movieron de su posición den-tro de la carcasa. | Retire las baterías y verifique que estén bien colocadas. Si continúa apagado, use el cargador incluido para recargarlas.
La interfaz gráfica no re-gistra los puntos al inter-actuar con un nodo acti-vo. | Presencia de obstáculos cer-canos o suciedad acumulada en la rejilla frontal del sensor. | Asegúrese de pasar la mano estrictamen-te dentro del rango de detección de 15 cm. Limpie suavemente la malla del sen-sor ultrasónico y despeje el área de juego.
La aplicación se queda congelada, no recibe da-tos o la respuesta es muy lenta. | Fallo temporal en la comuni-cación entre el nodo princi-pal y el sistema operativo del computador. | Desconecte el cable USB-C del nodo prin-cipal, espere 5 segundos y vuelva a co-nectarlo. Si el problema persiste, cambie el cable a otro puerto USB del compu-tador y reinicie la aplicación.

ò CONSEJO TÉCNICO DE RESPALDO

Alimentación Directa por Cable: Recuerde que cada una de las 4 carcasas (nodos sensoriales) incluye su propio puerto USB-C independiente. Si las baterías 18650 se descargan en medio de una actividad y no tiene tiempo de recargarlas, puede conectar un cable de alimentación directo a la caja para seguir utilizando el sistema sin interrupciones.

## 3 MANUAL TÉCNICO

### 3.1 Teoría de Operación

El sistema opera bajo una arquitectura en estrella sobre el protocolo ESP-NOW. El nodo maestro actúa como puente serial entre la red inalámbrica y el script de procesamiento en Python. La detección se basa en la medición de tiempo de vuelo de ondas ultrasónicas, procesadas localmente en cada ESP32-C3 para minimizar el tráfico de red.

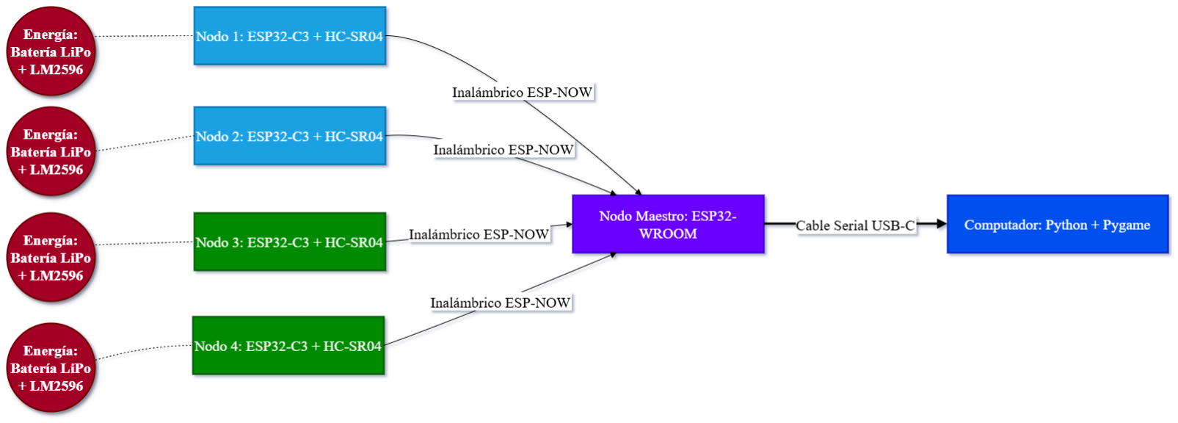
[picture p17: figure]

Figura 7: Topología de red y flujo de datos de DYNAMIC BEAT.

### 3.2 Lista de Materiales Ejecutada (BOM)

Componente | Cant. | Especificación | Costo Total
ESP32 C3 SuperMini | 2 | Microcontrolador Nodos | $ 18,696.00
ESP32 Wroom 32 | 1 | Microcontrolador Maestro | $ 14,481.95
Sensor HC-SR04 | 4 | Sensor de proximidad | $ 48,000.00
Batería LiPo 3.7V | 8 | Celdas de energía | $ 96,000.00
Carcasa PLA | 5 | Manufactura aditiva | $ 37,000.00
Otros Periféricos | – | Cables, Switches, PCB, LEDs | $ 106,428.88
TOTAL | 47 | Costo de Prototipado | $ 320,606.83

### 3.3 Plan de Mantenimiento Preventivo

Actividad | Frecuencia Procedimiento
Limpieza de Sensores Quincenal | Limpiar mallas con brocha de cerdas suaves.
Balanceo de Carga | Mensual | Ciclo de carga completa de baterías LiPo.
Inspección Mecánica | Trimestral | Revisión de soldadura en bornes de potencia.
Integridad de Datos | Semestral | Verificación de latencia 0.34s en consola.

### 3.4 Arquitectura de Firmware (Diagrama de Flujo)

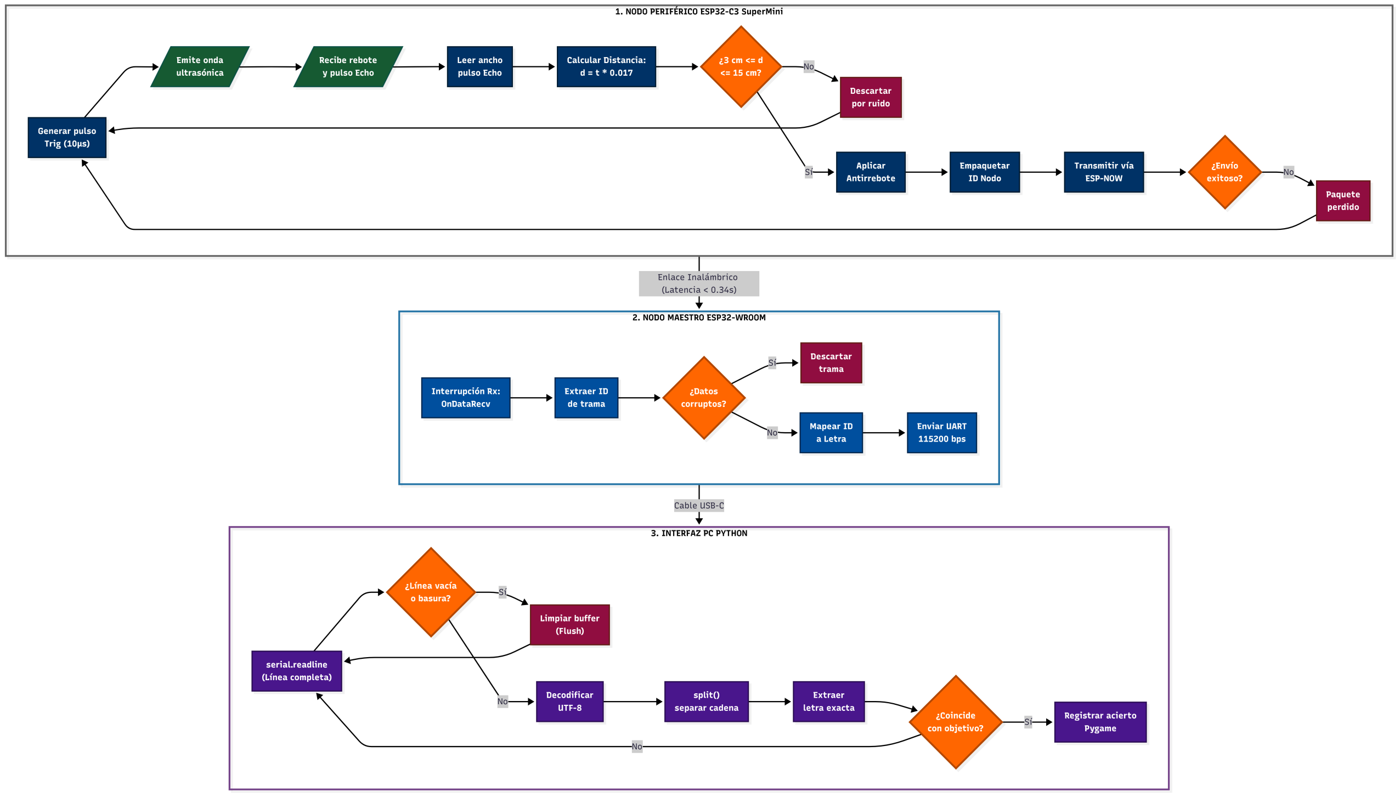
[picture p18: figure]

Figura 8: Diagrama de flujo del proceso lógico del sistema.

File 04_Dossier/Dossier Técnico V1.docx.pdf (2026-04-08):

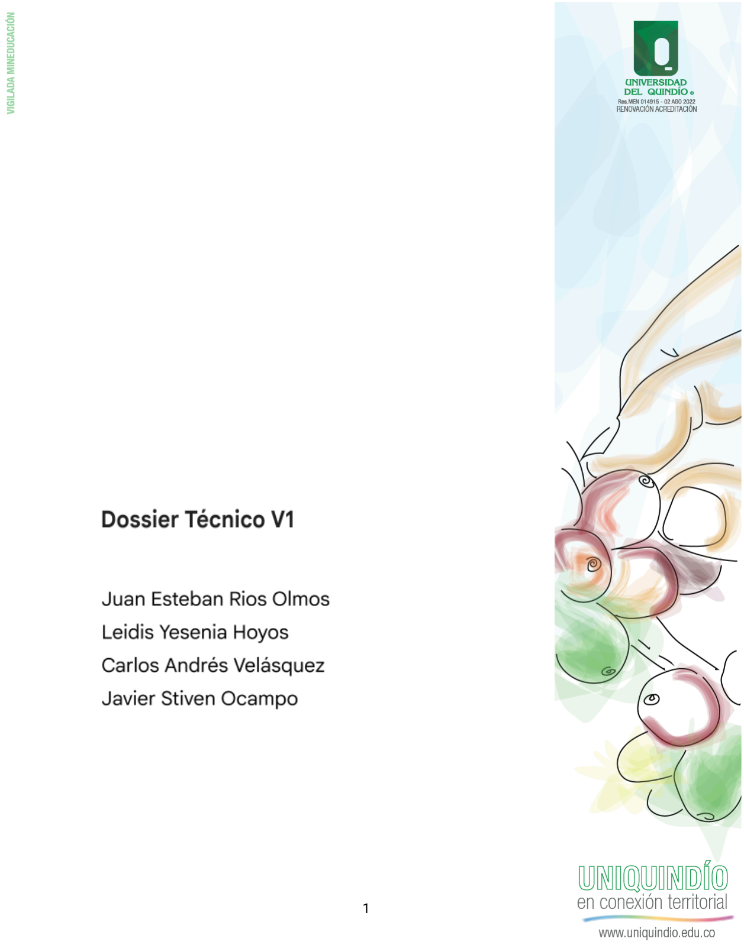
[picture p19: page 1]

### 1. Matriz de Defensa de Diseño (MDD)

Subsiste ma | Elemento Crítico | Veredicto (Pasa/Falla) | EVIDENCIA OBLIGATORIA (No Opiniones) | Acción Requerida
Energía | Baterías 3.7V | 🟢 Pasa | El sistema total consume ~300mA. Al usar 2 baterías de 2500mAh para alimentar el conjunto de 4 módulos (~150mA por batería). | Configurar gestión de carga. Asegurar que el circuito de protección (BMS) esté integrado en cada par de cajas inalámbricas.
Sensor | Sensor HC-SR04 | 🟢 Pasa | Reemplaza botones físicos para facilitar la terapia en pacientes con movilidad reducida (interacción sin contacto). Permite la separación inalámbrica de los objetivos. | Implementar un filtro de promedio móvil en el código para evitar los "falsos positivos" detectados en las pruebas de lab.
Control | ESP32 WROOM 32 | 🟢 Pasa | Funciona como Hub central para recibir datos de los 4 nodos mediante ESP-NOW. Su mayor capacidad de memoria permite gestionar la lógica del juego y la comunicación serial con el PC. | Diseñar el protocolo de emparejamiento para asegurar que el Maestro reconozca los 4 IDs únicos de los nodos esclavos.
Control | ESP32C3 Super Mini | 🟢 Pasa | Su tamaño reducido permite integrarlos en cajas pequeñas y ergonómicas. El | Programar los nodos en modo "Station" de bajo consumo para maximizar la vida útil

| | | protocolo ESP-NOW garantiza una latencia mínima en la transmisión de datos del sensor. | de las baterías entre sesiones.
Carcasa | Caja rectangular | 🟢 Pasa | El uso será exclusivo en interiores (Fundación Covida). Al no haber exposición solar directa, el PLA es apto ya que operará siempre por debajo de los 35°C. | Optimizar el espacio de las 4 cajas para distribuir bien los componentes.

### 2. BOM Final

Nivel | Ítem (Descrip ción) | MPN (Manufacturer Part Number) | Provee dor (Link) | Cost o Unit. | Tiempo de Entrega (Lead Time) | Semáforo de Riesgo
Bajo | Microco ntrolado r | ESP32 C3 SuperMini | AliExpre ss | $ 9.348 | Inmediato | 🟢 VERDE (Proceder)
Bajo | Microco ntrolado r | Placa OLED ESP32-C3 con módulo OLED | AliExpre ss | $ 10.81 4,44 | Inmediato | 🟢 VERDE (Proceder)
Bajo | Microco ntrolado r | esp32 wroom | AliExpre ss | $ 14.48 1,95 | Inmediato | 🟢 VERDE (Proceder)
Bajo | Sensor | Sensor HC:SR04 | Luloa | $ 12.00 0,00 | 2 Dias | 🟢 VERDE (Proceder)
Medi o | Batería LiPo | Generica 3.7V | Luloa | $ 12.00 0,00 | 2 Dias | 🟢 VERDE (Proceder)
Medi o | Regulad or | LM2596 | Luloa | $ 14.0 00,0 | 2 Dias | 🟢 VERDE (Proceder)

| | | | 0
Bajo | caja | caja | Luloa | $ 7.40 0,00 | 2 Dias | 🟢 VERDE (Proceder)

### 3. Evidencias de Auditoría

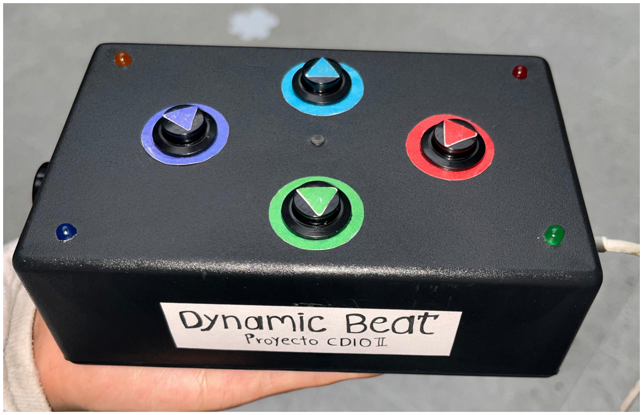
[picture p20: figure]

Imagen 1. Vista superior del prototipo.

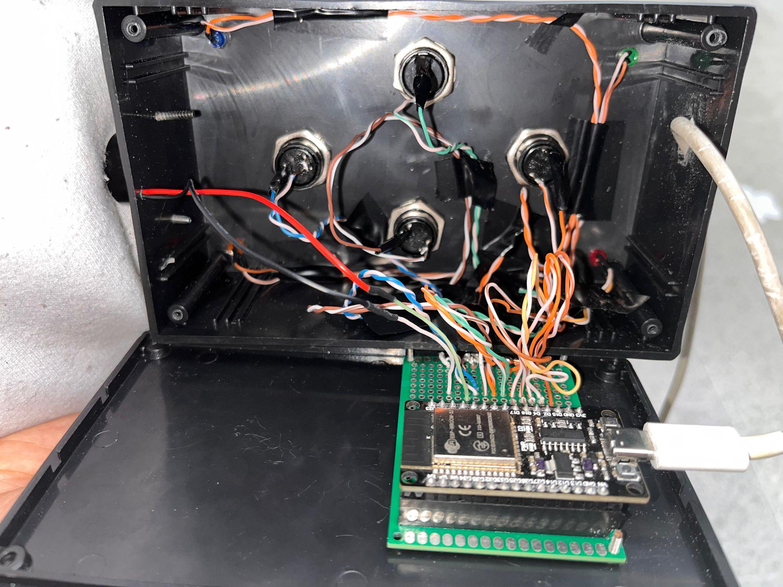
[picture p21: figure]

Imagen 2. Interior del prototipo.

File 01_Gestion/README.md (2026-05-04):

##  Dashboard del Proyecto

Puede consultar el estado del proyecto, tareas y avances en el siguiente enlace:

🔗 [Ver Dashboard en GitHub Projects](https://docs.google.com/spreadsheets/d/16BMT0KwvYPv9AQtpj7Zw0qbRo2MVD9Crjc564nbe30I/edit?usp=sharing)

 main
Gestión del Proyecto
La administración y desarrollo del proyecto Dynamic Beat se fundamenta en una división clara de responsabilidades técnicas y un flujo de trabajo estructurado para garantizar la correcta integración de hardware y software.

Roles y Responsabilidades del Equipo
El desarrollo del sistema está distribuido según las fortalezas técnicas de cada integrante:

Desarrollo de Hardware y Control: Responsable de la programación de los microcontroladores ESP32 (nodos y maestro), implementación del protocolo de comunicación ESP-NOW, diseño de circuitos (PCB) y la integración del control de datos mediante MATLAB y Simulink. (Carlos)

Gestión Documental y Repositorio: Encargada de la administración del control de versiones en GitHub, estructuración de archivos, estandarización de la documentación técnica y mantenimiento del repositorio. (Leidis)

Caracterización y Soporte Académico: A cargo de la caracterización de los sistemas, modelado matemático, validación de parámetros técnicos y propiedad de los entregables académicos del curso. (Daniel González)

Flujo de Trabajo y Control de Versiones
Para mantener la trazabilidad del código y de los esquemas electrónicos, el equipo utiliza las siguientes prácticas en GitHub:

Gestión de Tareas (Issues): Cualquier implementación nueva, como la validación de detección de los sensores ultrasónicos o la sincronización de red, debe registrarse previamente como un Issue para hacer seguimiento a su estado.

Convención de Commits: Los cambios subidos al repositorio deben contar con mensajes descriptivos que indiquen claramente qué sección del proyecto fue modificada (código de nodos, diagramas, esquemas de potencia).

Integración de Cambios: El desarrollo de características individuales se prueba exhaustivamente en el hardware antes de ser integrado a la rama principal, asegurando que no haya pérdida de paquetes en la comunicación ni fallos en el registro de datos.

Organización de la Documentación
Toda la información del proyecto se encuentra segmentada en directorios específicos para separar el código fuente de los nodos, los archivos de diseño electromecánico e impresión 3D, y los protocolos de pruebas físicas ejecutados.

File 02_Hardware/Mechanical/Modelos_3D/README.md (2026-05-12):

# Modelos 3D

En esta carpeta se guardan los archivos 3D para imprimir las carcasas del proyecto Dynamic Beat. Aquí solo encontrarás:

- El diseño para las cajas de los 4 nodos periféricos (las cuatro son exactamente iguales).
- El diseño para la caja principal o nodo maestro, que tiene una forma diferente a las demás.

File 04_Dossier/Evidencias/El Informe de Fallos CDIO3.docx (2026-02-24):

Título: Informe Técnico de Evaluación de Componentes Heredados – Botonera Física

Proyecto: Dynamic Beat

Auditor: Juan Esteban (Líder de Auditoría e Integración)

Introducción: Se realizó una auditoría técnica a la interfaz de entrada física (botones) heredada del diseño inicial. El objetivo era validar si cumplía con los requerimientos de usabilidad para los pacientes de la Fundación Covida.

Hallazgos de Fallos:

- Fallo Mecánico (Dificultad de Pulsación): Los pulsadores seleccionados requieren una fuerza de actuación superior a los 300g. Esto es una barrera crítica para pacientes con movilidad reducida o debilidad muscular severa, invalidando el propósito de una terapia fluida.
- Fallo de Autonomía: El diseño de la botonera exige que un tercero sostenga el dispositivo o asista al paciente en cada pulsación. Esto viola el principio de autonomía del usuario buscado en el proyecto.
- Fallo de Señal (Ruido Eléctrico): Se detectó "rebote" (bouncing) constante en las lecturas, lo que generaba múltiples registros de una sola pulsación, afectando la precisión de los datos enviados al juego en Python.

Conclusión y Acción: Debido a estos fallos, se concluye que la botonera física no es apta para el sistema. Se justifica la integración del sensor ultrasónico HC-SR04, el cual elimina el contacto físico y permite una interacción basada en proximidad, cumpliendo con los estándares de calidad y accesibilidad requeridos.

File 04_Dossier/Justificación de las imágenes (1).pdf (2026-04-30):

Influencia de la Temperatura de Color y el Modo de Pantalla en la Fatiga Ocular:

Xie, X., Yu, S., & Chen, D. (2025). Efectos del modo de color de la pantalla y la temperatura de color en la fatiga visual bajo diferentes iluminaciones ambientales. International Journal of Human–Computer Interaction , 41 (2), 821–833. https://doi.org/10.1080/10447318.2024.2305982

El uso prolongado de pantallas electrónicas puede causar fatiga visual e incluso provocar problemas oculares como errores de refracción, sequedad ocular, etc. La relación entre la visualización en pantalla y la fatiga visual ha recibido mucha atención. Este artículo tiene como objetivo estudiar la temperatura de color y el modo de color óptimos de la pantalla bajo dos iluminaciones ambientales comunes: iluminación normal de oficina (450 lux) y ambiente oscuro (3 lux). En un diseño experimental de 2 × 2 × 3, 36 participantes evaluaron los efectos de dos modos de color de pantalla (modo claro y modo oscuro) y tres temperaturas de color de pantalla (2800 K, 4500 K y 6500 K) sobre la fatiga visual bajo dos iluminaciones ambientales. Utilizamos tecnología de seguimiento del movimiento ocular para recopilar la frecuencia de parpadeo y los diámetros pupilares como indicadores objetivos y la escala de Richter para recopilar la fatiga visual subjetiva y la puntuación de preferencia como indicadores subjetivos. Los resultados mostraron que, a 450 lux, se observó menor fatiga visual en el modo oscuro, con temperaturas de color de 4500 K y 6500 K. A 3 lux, la fatiga visual fue menor en el modo oscuro y con una temperatura de color de 4500 K. Tanto de día como de noche, la temperatura de color de 2800 K produjo la mayor fatiga visual. Nuestros hallazgos complementan la investigación sobre pantallas y fatiga visual, y tienen implicaciones prácticas para reducir la fatiga visual causada por el uso prolongado de pantallas electrónicas.

Requisitos Ergonómicos Internacionales para Pantallas Electrónicas:

Organización Internacional de Normalización. (2011). Ergonomics of human-system interaction — Part 303: Requirements for electronic visual displays (ISO Standard No. 9241-303:2011). https://www.iso.org/standard/57992.html

La norma ISO 9241-303:2011 establece los requisitos de calidad de imagen y proporciona directrices para las pantallas electrónicas. Estas se presentan en forma de especificaciones de rendimiento genéricas (independientes de la tecnología, la tarea y el entorno) y recomendaciones que garantizan una visualización eficaz y cómoda para usuarios con visión normal o adaptada a la normalidad.

Estrategias Clínicas y Preventivas para la Fatiga Visual Digital:
Coles-brennan, C., Sulley, A., & Young, G. (2019). Manejo de la fatiga visual digital. Clinical and Experimental Optometry , 102 (1), 18-29. https://doi.org/10.1111/cxo.12798

La fatiga visual digital, un problema emergente de salud pública, es una condición caracterizada por alteraciones visuales y/o molestias oculares relacionadas con el uso de dispositivos digitales y resultantes de una variedad de estrés en el entorno ocular. Esta revisión tiene como objetivo proporcionar una visión general de la extensa literatura sobre la investigación de la fatiga visual digital con especial referencia al manejo clínico de los síntomas. Hasta el 90 por ciento de los usuarios de dispositivos digitales experimentan síntomas de fatiga visual digital. Muchos estudios sugieren que los siguientes factores están asociados con la fatiga visual digital: error refractivo no corregido (incluida la presbicia), anomalías de acomodación y vergencia, patrón de parpadeo alterado (frecuencia reducida y parpadeo incompleto), exposición excesiva a luz intensa, distancia de trabajo más cercana y tamaño de fuente más pequeño. Dado que un síntoma puede ser causado por uno o más factores, se debe adoptar un enfoque holístico. Se han sugerido las siguientes estrategias de manejo: (i) corrección apropiada del error refractivo, incluido el astigmatismo y la presbicia; (ii) manejo de anomalías de vergencia, con el objetivo de inducir o dejar una pequeña cantidad de heteroforia (~1.5 Δ Exo); (iii) ejercicio/entrenamiento de parpadeo para mantener un patrón de parpadeo normal; (iv) uso de gotas lubricantes para los ojos (lágrimas artificiales) para ayudar a aliviar los síntomas relacionados con el ojo seco; (v) lentes de contacto con mayor comodidad, particularmente al final del día y en entornos difíciles; (vi) prescripción de filtros de color en todas las opciones de corrección de la visión, especialmente filtros que absorben la luz azul; y (vii) manejo de anomalías de acomodación. La prevención es la estrategia principal para el manejo de la fatiga visual digital, que implica:
(i) asegurar un entorno y práctica de trabajo ergonómicos (a través de la educación del paciente y la implementación de políticas ergonómicas en el lugar de trabajo); y (ii) examen visual y cuidado de los ojos para tratar los trastornos visuales. Se necesita una consideración especial para las personas con alto riesgo de fatiga visual digital, como los trabajadores de computadoras y los usuarios de lentes de contacto.

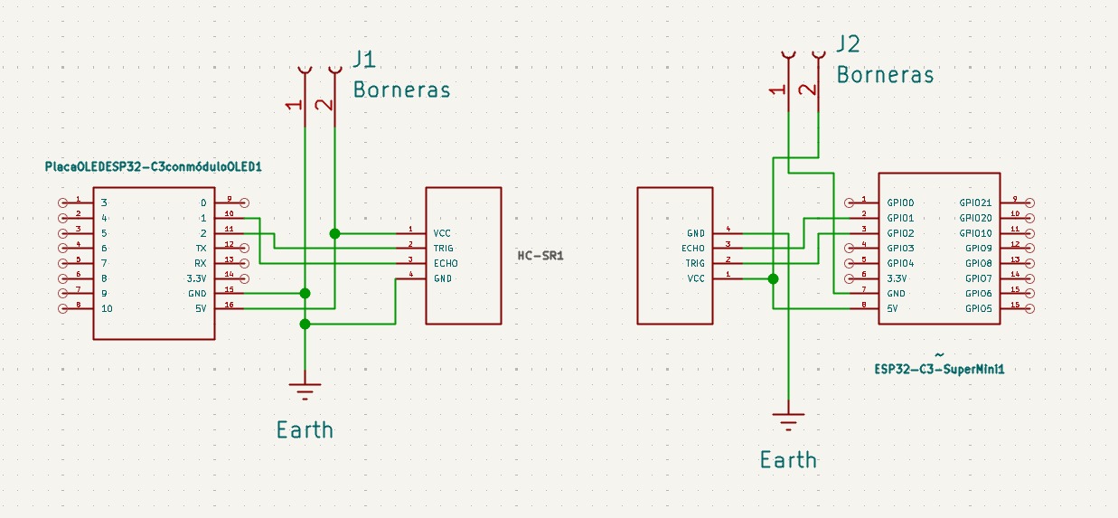
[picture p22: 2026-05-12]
04_Dossier/Evidencias/Diseño_del_circuito.jpeg

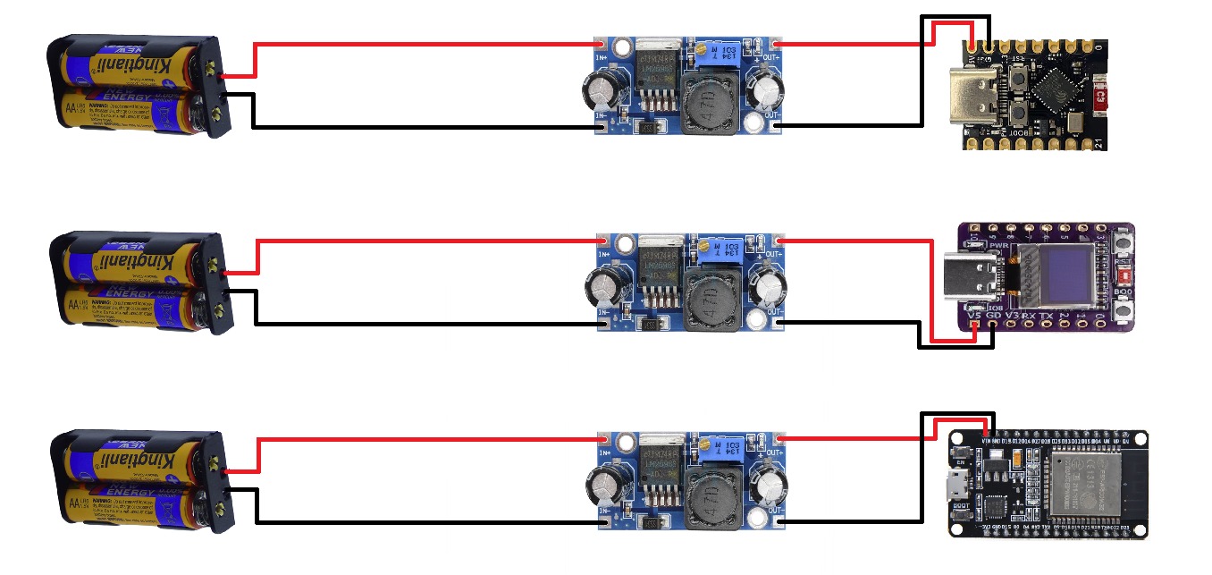
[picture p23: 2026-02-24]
02_Hardware/Source/esquematico_conexión_fuente-esp.jpeg

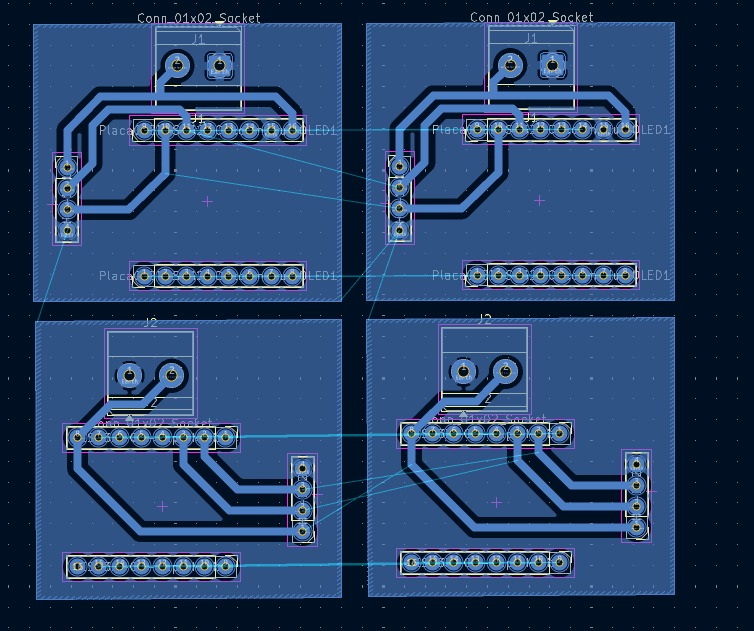
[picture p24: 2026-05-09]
04_Dossier/Evidencias/Diseño_final_(PCB).jpeg

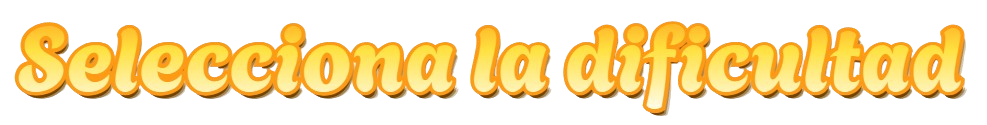
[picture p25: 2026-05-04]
03_Firmware/src/Codigo_Interfaz_Proyecto_CDIO/assets/Seleccionmodo.png

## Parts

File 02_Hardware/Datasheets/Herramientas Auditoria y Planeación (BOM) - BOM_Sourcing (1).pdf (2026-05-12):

Nivel | Ítem (Descripción) | MPN (Manufacturer Part Number) | Proveedor (Link) | Costo Unit. | Tiempo de Entrega (Lead Time) | Semáforo de Riesgo
Bajo | Microcontrolador | ESP32 C3 SuperMini | AliExpress | $ 9.348 | Inmediato | VERDE (Proceder)
Bajo | Microcontrolador | Placa OLED ESP32-C3 con módulo OLED | AliExpress | $ 10.814,44 | Inmediato | VERDE (Proceder)
Bajo | Microcontrolador | ESP32 WROOM 32 | AliExpress | $ 14.481,95 | Inmediato | VERDE (Proceder)
Bajo | Sensor | Sensor HC:SR04 | Luloa | $ 12.000,00 | Inmediato | VERDE (Proceder)
Bajo | Batería LiPo | Generica 3.7V | Luloa | $ 12.000,00 | 2 Dias | VERDE (Proceder)
Bajo | Portapilas | Portapilas para las baterias LiPo | Luloa | $ 4.000 | 2 Dias | VERDE (Proceder)
Bajo | Cargador | Cargador de las baterias | Luloa | $ 14.000,00 | 3 Dias | VERDE (Proceder)
Bajo | Regulador | LM2596 | Luloa | $ 14.000,00 | 2 Dias | VERDE (Proceder)
Bajo | Caja | Caja | Luloa | $ 7.400,00 | Inmediato | VERDE (Proceder)
Bajo | PCB | PCB impresa | Luloa | $ 2.400 | 2 Dias | VERDE (Proceder)
Bajo | Borneas | Borneras de alimenación | Luloa | $ 800 | Inmediato | VERDE (Proceder)
Bajo | Regletas de pines | Regletas para los componentes | Luloa | $ 2.000 | Inmediato | VERDE (Proceder)
Bajo | Cable USB-C | Cable USB-C para el Microcontrolador Maestro | Miniso | $ 20.000 | Inmediato | VERDE (Proceder)
Bajo | LED RGB | LED RGB indicador | Luloa | $ 1.000 | Inmediato | VERDE (Proceder)
Bajo | Resistencias para el LED | Resistencias de 100 y 39 Ohms | Luloa | $ 200 | Inmediato | VERDE (Proceder)
Bajo | Soldadura | Estaño 1 metro | Luloa | $ 2.000 | Inmediato | VERDE (Proceder)
Bajo | Switch de palanca | Switch de encendido | Luloa | $ 800 | Inmediato | VERDE (Proceder)
Bajo | Decoración | Papel sticker | Papeleria | $2000 | Inmediato | VERDE (Proceder)

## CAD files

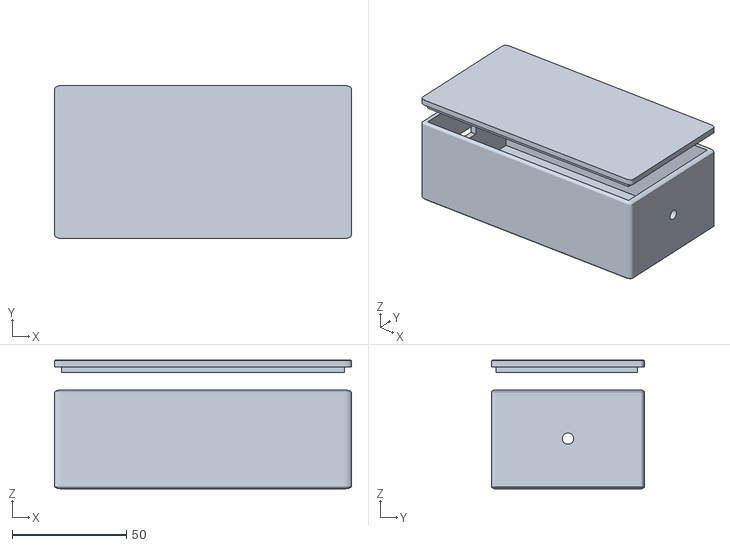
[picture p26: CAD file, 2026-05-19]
02_Hardware/Mechanical/Modelos_3D/Caja CDIO.stl
130.0 x 67.0 x 56.3

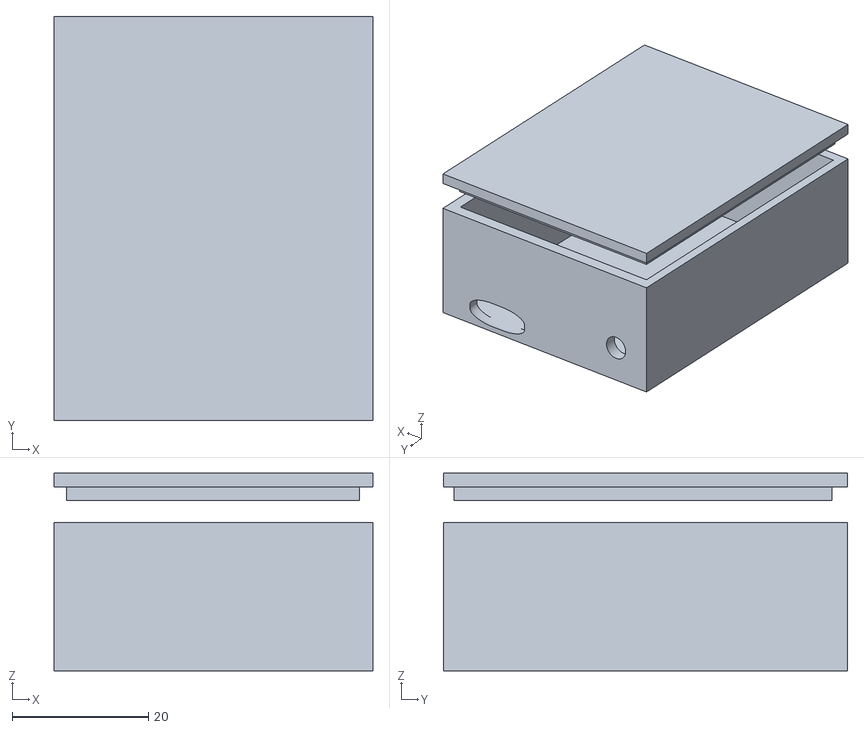
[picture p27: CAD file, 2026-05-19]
02_Hardware/Mechanical/Modelos_3D/Caja CDIO Maestro.stl
46.8 x 59.3 x 29.0

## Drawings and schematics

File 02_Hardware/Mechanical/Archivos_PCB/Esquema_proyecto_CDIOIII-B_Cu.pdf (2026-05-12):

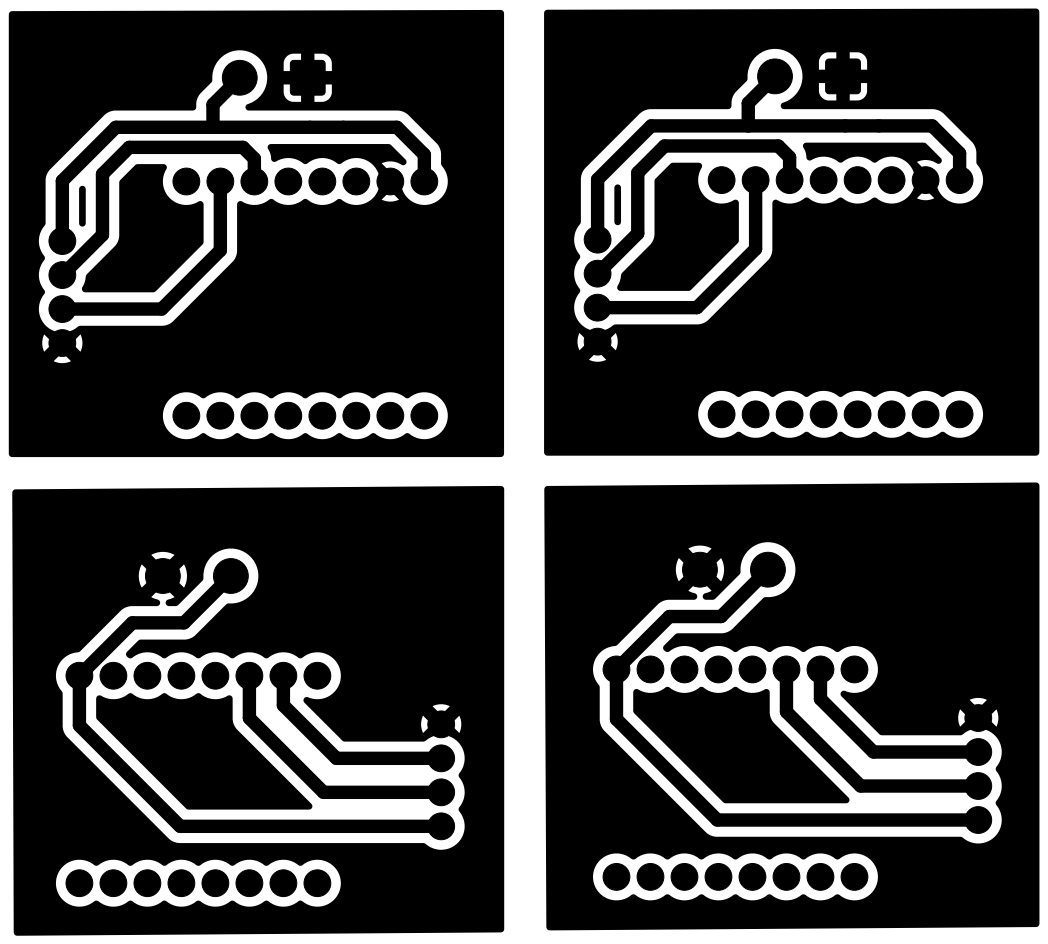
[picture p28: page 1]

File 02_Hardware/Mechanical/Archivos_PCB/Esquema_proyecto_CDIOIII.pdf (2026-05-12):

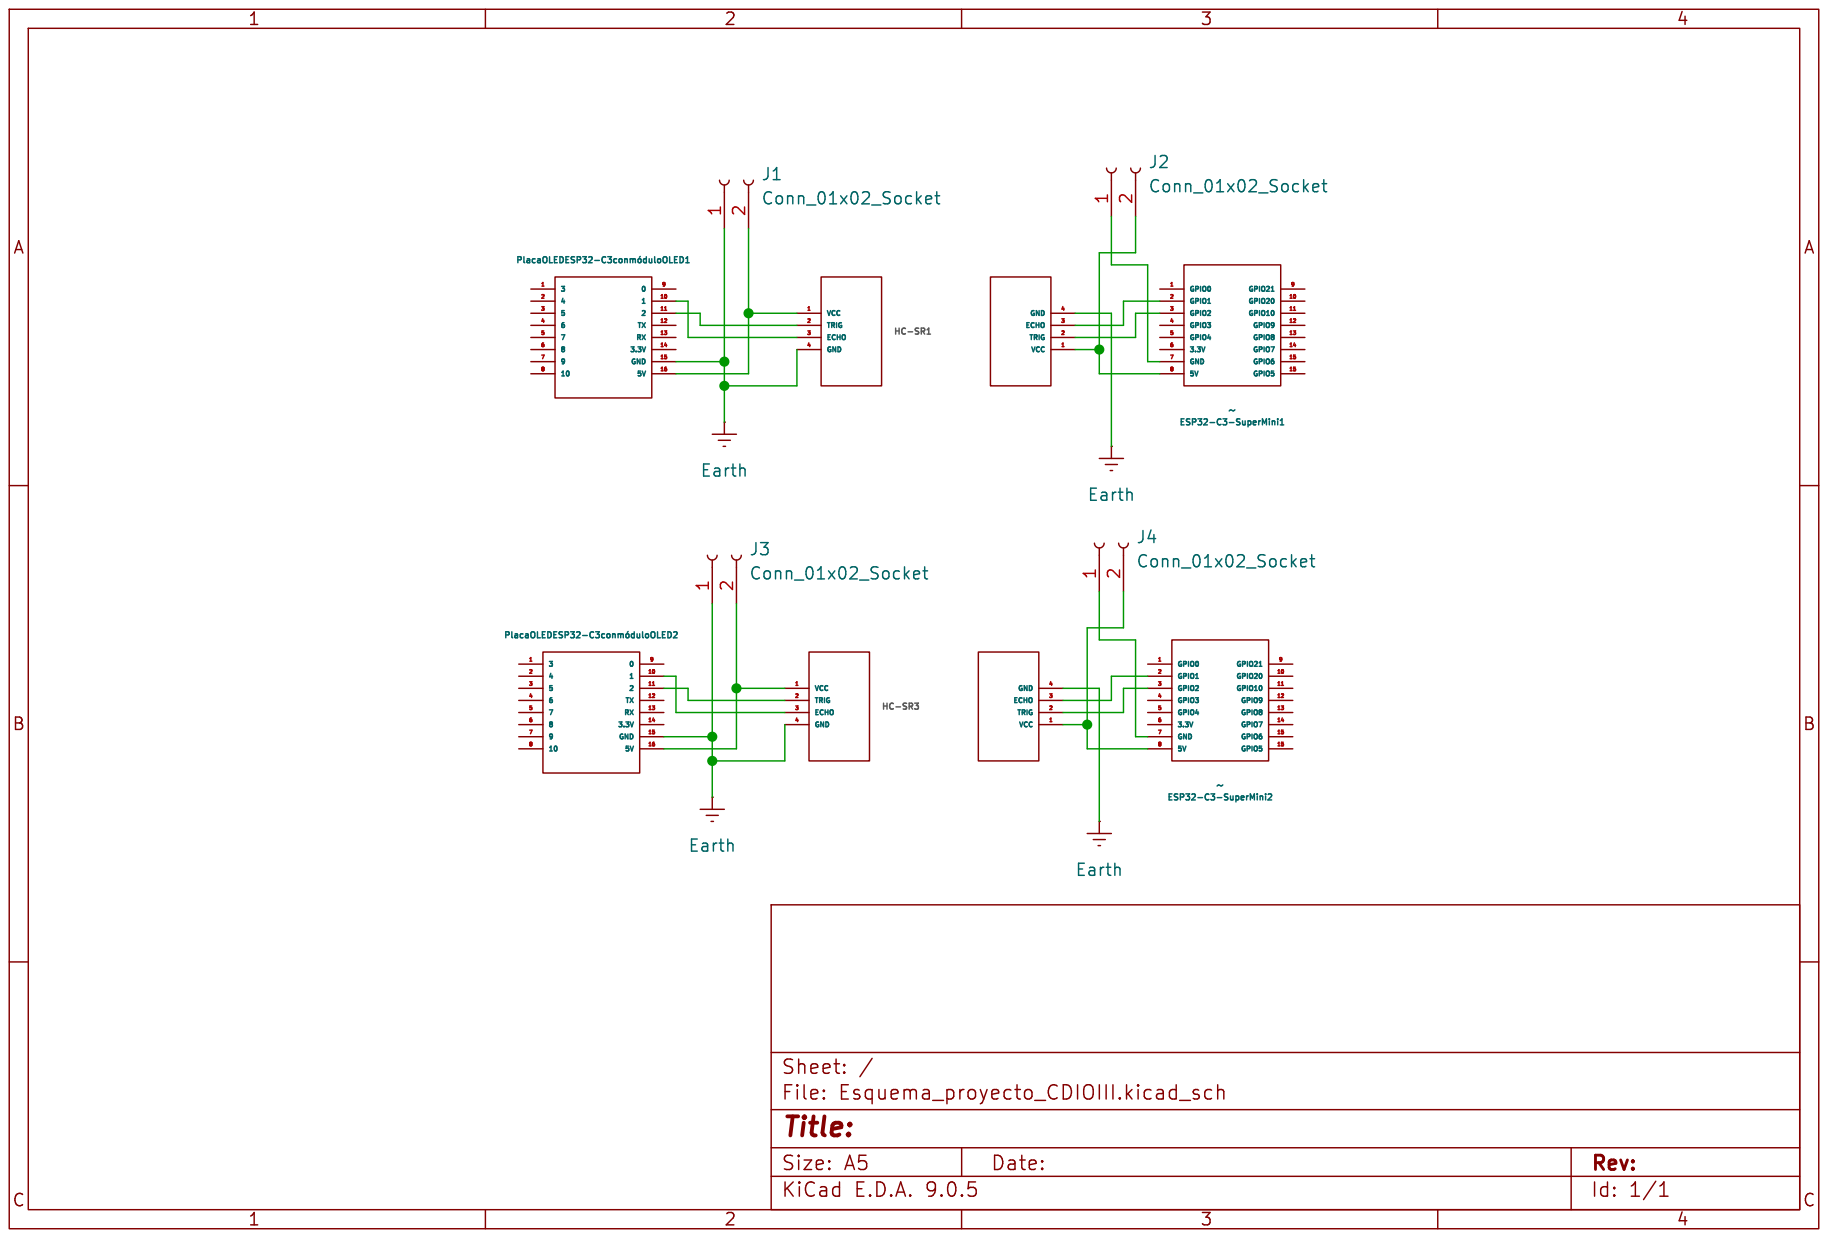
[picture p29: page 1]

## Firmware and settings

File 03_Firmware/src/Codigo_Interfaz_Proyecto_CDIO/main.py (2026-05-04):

import pygame
import random
import sys
import os
import serial

# --- INICIO DE CONEXIÓN SERIAL ---
try:
    # Ajustado a 115200 baudios como configuraste en el ESP32
    puerto_serial = serial.Serial('COM4', 115200, timeout=0.01) 
    print("ESP32 conectado correctamente.")
except serial.SerialException:
    print("Error: No se pudo conectar al puerto serial. Verifica el COM.")
    puerto_serial = None

# Inicializar Pygame
pygame.init()

# Configuración de pantalla
ANCHO, ALTO = 800, 700
VENTANA = pygame.display.set_mode((ANCHO, ALTO))
pygame.display.set_caption("Dynamic Beat - Versión Profesional")

# Colores
AZUL = (0, 120, 255)
VERDE = (0, 255, 150)
BLANCO = (255, 255, 255)
NEGRO = (0, 0, 0)
MARRON = (101, 67, 33)
NARANJA = (255, 203, 61)

# --- RUTAS E IMÁGENES ---
ruta_imagenes = "C:\\Users\\Javier S Ocampo\\Documents\\Juego CDIO\\Imagenes"

# Fuentes de sistema
pygame.font.init()
FUENTE = pygame.font.Font(os.path.join(ruta_imagenes, "KGPerfectPenmanship.ttf"), 30)
FUENTE_TITULO_GRANDE = pygame.font.Font(os.path.join(ruta_imagenes, "Astromeda PERSONAL USE ONLY!.ttf"), 115)
FUENTE_CUSTOM_INSTR = pygame.font.Font(os.path.join(ruta_imagenes, "KGPerfectPenmanship.ttf"), 38)
FUENTE_CUSTOM_INSTR.set_bold(False)
FUENTE_PUNTAJE = pygame.font.Font(os.path.join(ruta_imagenes, "Super Chips.ttf"), 33)

# Carga de imágenes generales (Optimizadas para cargarse 1 sola vez)
IMAGENES_FLECHAS = {
    '↑': pygame.transform.scale(pygame.image.load(os.path.join(ruta_imagenes, "BotonVerde.png")), (250, 130)),
    '↓': pygame.transform.scale(pygame.image.load(os.path.join(ruta_imagenes, "BotonAzul.png")), (250, 130)),
    '←': pygame.transform.scale(pygame.image.load(os.path.join(ruta_imagenes, "BotonRojo.png")), (250, 130)),
    '→': pygame.transform.scale(pygame.image.load(os.path.join(ruta_imagenes, "BotonAmarillo.png")), (250, 130)),
}
STICKMAN_ACIERTO = pygame.transform.scale(pygame.image.load(os.path.join(ruta_imagenes, "StickmanAcierto.png")), (190, 200))
STICKMAN_ACIERTO_2 = pygame.transform.scale(pygame.image.load(os.path.join(ruta_imagenes, "StickmanAcierto2.png")), (190, 200))
STICKMAN_FALLO = pygame.transform.scale(pygame.image.load(os.path.join(ruta_imagenes, "StickmanFallo.png")), (190, 200))
FONDO_IMG = pygame.transform.scale(pygame.image.load(os.path.join(ruta_imagenes, "Fondo5.png")), (800, 700))
FONDO_CUADRO_BASE = pygame.image.load(os.path.join(ruta_imagenes, "CuadroInstrucciones.png"))

# Imágenes UI de pantallas (Movidas aquí para no cargarlas en bucles)
IMG_PANEL_PUNTAJE = pygame.transform.smoothscale(pygame.image.load(os.path.join(ruta_imagenes, "Puntaje.png")), (560, 555))
IMG_BOTON_REINICIAR = pygame.transform.scale(pygame.image.load(os.path.join(ruta_imagenes, "Reiniciar.png")), (220, 110))
IMG_BOTON_SALIR = pygame.transform.scale(pygame.image.load(os.path.join(ruta_imagenes, "Salir2.png")), (190, 90))
IMG_ESTRELLITA = pygame.transform.smoothscale(pygame.image.load(os.path.join(ruta_imagenes, "Estrella.png")), (131, 131))
IMG_ESTRELLA = pygame.transform.smoothscale(pygame.image.load(os.path.join(ruta_imagenes, "Estrella.png")), (169, 169))
IMG_INSTRUCCIONES_TITULO = pygame.transform.scale(pygame.image.load(os.path.join(ruta_imagenes, "Instrucciones.png")), (600, 110))
IMG_MODO_TITULO = pygame.transform.scale(pygame.image.load(os.path.join(ruta_imagenes, "Seleccionmodo.png")), (735, 125))
IMG_BOTON_NOVATO = pygame.transform.scale(pygame.image.load(os.path.join(ruta_imagenes, "Facil.png")), (214, 98))
IMG_BOTON_MEDIO = pygame.transform.scale(pygame.image.load(os.path.join(ruta_imagenes, "Medio.png")), (219, 102))
IMG_BOTON_DIFICIL = pygame.transform.scale(pygame.image.load(os.path.join(ruta_imagenes, "Dificil.png")), (240, 124))
IMG_BOTON_JUGAR = pygame.transform.scale(pygame.image.load(os.path.join(ruta_imagenes, "Jugar.png")), (214, 130))
IMG_BOTON_SALIR_INICIO = pygame.transform.scale(pygame.image.load(os.path.join(ruta_imagenes, "Salir1.png")), (205, 104))

# Carga de las imágenes para la zona de juego
IMG_ZONA_1 = pygame.image.load(os.path.join(ruta_imagenes, "PulVerde.png"))
IMG_ZONA_2 = pygame.image.load(os.path.join(ruta_imagenes, "PulAzul.png"))
IMG_ZONA_3 = pygame.image.load(os.path.join(ruta_imagenes, "PulRojo.png"))
IMG_ZONA_4 = pygame.image.load(os.path.join(ruta_imagenes, "PulAmarillo.png"))

size_img = (250, 130)
img_z1 = pygame.transform.scale(IMG_ZONA_1, size_img)
img_z2 = pygame.transform.scale(IMG_ZONA_2, size_img)
img_z3 = pygame.transform.scale(IMG_ZONA_3, size_img)
img_z4 = pygame.transform.scale(IMG_ZONA_4, size_img)

pos_z1 = (ANCHO // 2 - 250, 525)
pos_z2 = (ANCHO // 2 - 404, 525)
pos_z3 = (ANCHO // 2 + 15, 525)
pos_z4 = (ANCHO // 2 + 154, 525)

# Configuración de flechas
DIRECCIONES = ['↑', '↓', '←', '→']
# B = Verde (Arriba), A = Azul (Abajo), C = Rojo (Izquierda), D = Amarillo (Derecha)
LETRAS_SERIAL = {'B': '↑', 'A': '↓', 'C': '←', 'D': '→'}
POSICIONES_FLECHAS = {'↑': ANCHO // 2 - 200, '↓': ANCHO // 2 - 355, '←': ANCHO // 2 + 61, '→': ANCHO // 2 + 202}
ZONA_ACTIVACION_Y = 590
ALTURA_ZONA = 150
VELOCIDAD_FLECHA = 2
TOTAL_RONDAS = 20

# --- OPTIMIZACIÓN: PRECALCULAR EL RESPLANDOR (GLOW) ---
glow_ancho, glow_alto = ANCHO - 100, ALTURA_ZONA
SUPERFICIE_GLOW = pygame.Surface((glow_ancho + 60, glow_alto + 60), pygame.SRCALPHA)
for i in range(1, 26):
    intensidad = int(8 + 247 * (1 - (i / 25))**1.5)
    color = (0, 255, 255, intensidad)
    pygame.draw.rect(SUPERFICIE_GLOW, color, (30 - i, 30 - i, glow_ancho + i * 2, glow_alto + i * 2), width=2, border_radius=10)
pygame.draw.rect(SUPERFICIE_GLOW, (255, 255, 255, 255), (30, 30, glow_ancho, glow_alto), width=2, border_radius=10)


class Flecha:
    def __init__(self, direccion):
        self.direccion = direccion
        self.x = POSICIONES_FLECHAS[direccion]
        self.y = -50
        self.activa = True
        self.imagen = IMAGENES_FLECHAS[direccion]
    def mover(self):
        self.y += VELOCIDAD_FLECHA
        if self.y > ALTO + 50: self.activa = False
    def dibujar(self, ventana):
        ventana.blit(self.imagen, (self.x - 50, self.y - 50))

class Muñeco:
    def __init__(self):
        self.x = 370
        self.y = ALTO - 210
        self.estado = "fallo"
        self.timer_acierto = 0
        self.frame_actual = 1  # <--- NUEVO: Controla qué animación mostrar

    def cambiar_estado(self, estado):
        if estado == "acierto":
            self.estado = "acierto"
            self.timer_acierto = pygame.time.get_ticks()
            
            # ---  Alternar entre la imagen 1 y la 2 ---
            if self.frame_actual == 1:
                self.frame_actual = 2
            else:
                self.frame_actual = 1
        else: 
            self.estado = "fallo"

    def dibujar(self, ventana):
        tiempo_actual = pygame.time.get_ticks()
        if self.estado == "acierto" and tiempo_actual - self.timer_acierto > 500: 
            self.estado = "fallo"
            
        if self.estado == "acierto":
            if self.frame_actual == 1:
                imagen = STICKMAN_ACIERTO
            else:
                imagen = STICKMAN_ACIERTO_2
        else:
            imagen = STICKMAN_FALLO
            
        ventana.blit(imagen, (self.x - 60, self.y))

def dibujar_fondo():
    VENTANA.blit(FONDO_IMG, (0, 0))

def dibujar_zona_activacion():
    x, y = (ANCHO - glow_ancho) // 2, ZONA_ACTIVACION_Y - ALTURA_ZONA // 2
    VENTANA.blit(SUPERFICIE_GLOW, (x - 30, y - 30))

def render_texto_con_borde(texto, fuente, color_texto, color_borde):
    base = fuente.render(texto, True, color_texto)
    superficie = pygame.Surface((base.get_width() + 2, base.get_height() + 2), pygame.SRCALPHA)
    for dx in range(-1, 2):
        for dy in range(-1, 2):
            if dx != 0 or dy != 0:
                superficie.blit(fuente.render(texto, True, color_borde), (dx + 1, dy + 1))
    superficie.blit(base, (1, 1))
    return superficie


# --- PANTALLAS DEL JUEGO ---
def pantalla_instrucciones():
    esperando = True
    progreso = 0
    velocidad_escritura = 0.5
    reloj = pygame.time.Clock()

    lineas = [
        "Pase la mano o la pierna por encima  ",
        "del  sensor  del   mismo   color   que    ",
        "el   indicador   de   su   extremidad,  ",
        "únicamente  cuando  los  círculos se ",
        "encuentren dentro del recuadro ",
        "blanco", "",
        "Presiona CUALQUIER TECLA", "para continuar..."
    ]
    total_caracteres = sum(len(l) for l in lineas)

    ancho_caja, alto_caja = 750, 525
    x_caja = (ANCHO // 2) - (ancho_caja // 2)
    y_caja = 140
    cuadro_inst = pygame.transform.scale(FONDO_CUADRO_BASE, (ancho_caja, alto_caja))

    while esperando:
        reloj.tick(60)
        dibujar_fondo()
        VENTANA.blit(cuadro_inst, (x_caja, y_caja))
        VENTANA.blit(IMG_INSTRUCCIONES_TITULO, (ANCHO // 2 - IMG_INSTRUCCIONES_TITULO.get_width() // 2, 60))

        texto_x, texto_y = 90, 200
        caracteres_acumulados = 0
        for i, linea in enumerate(lineas):
            if int(progreso) > caracteres_acumulados:
                limite_linea = int(progreso) - caracteres_acumulados
                texto_parcial = linea[:limite_linea]
                if "Presiona" in linea or "continuar" in linea:
                    texto_render = FUENTE_CUSTOM_INSTR.render(texto_parcial, True, NEGRO)
                else:
                    texto_render = render_texto_con_borde(texto_parcial, FUENTE_CUSTOM_INSTR, BLANCO, NEGRO)
                VENTANA.blit(texto_render, (texto_x, texto_y + i * 45))
            caracteres_acumulados += len(linea)

        if progreso < total_caracteres: progreso += velocidad_escritura
        pygame.display.update()

        for evento in pygame.event.get():
            if evento.type == pygame.QUIT: pygame.quit(); sys.exit()
            if evento.type == pygame.KEYDOWN or evento.type == pygame.MOUSEBUTTONDOWN:
                if progreso < total_caracteres: progreso = total_caracteres
                else: esperando = False

def pantalla_instrucciones_2():
    esperando = True
    progreso = 0
    velocidad_escritura = 0.5
    reloj = pygame.time.Clock()

    lineas = [
        "En caso de no pasar por encima del ",
        "sensor, no se obtendrán puntos   ",
        "negativos; sin embargo, si se pasa  ",
        "por encima de un sensor incorrecto, ",
        "se sumará un punto negativo.",
        "Todas las rondas son de 20 puntos.", "",
        "Presiona CUALQUIER TECLA ", "para continuar..."
    ]
    total_caracteres = sum(len(l) for l in lineas)

    ancho_caja, alto_caja = 750, 525
    x_caja = (ANCHO // 2) - (ancho_caja // 2)
    y_caja = 140
    cuadro_inst = pygame.transform.scale(FONDO_CUADRO_BASE, (ancho_caja, alto_caja))

    while esperando:
        reloj.tick(60)
        dibujar_fondo()
        VENTANA.blit(cuadro_inst, (x_caja, y_caja))
        VENTANA.blit(IMG_INSTRUCCIONES_TITULO, (ANCHO // 2 - IMG_INSTRUCCIONES_TITULO.get_width() // 2, 60))

        texto_x, texto_y = 90, 200
        caracteres_acumulados = 0
        for i, linea in enumerate(lineas):
            if int(progreso) > caracteres_acumulados:
                limite_linea = int(progreso) - caracteres_acumulados
                texto_parcial = linea[:limite_linea]
                if "Presiona" in linea or "continuar" in linea:
                    texto_render = FUENTE_CUSTOM_INSTR.render(texto_parcial, True, NEGRO)
                else:
                    texto_render = render_texto_con_borde(texto_parcial, FUENTE_CUSTOM_INSTR, BLANCO, NEGRO)
                VENTANA.blit(texto_render, (texto_x, texto_y + i * 45))
            caracteres_acumulados += len(linea)

        if progreso < total_caracteres: progreso += velocidad_escritura
        pygame.display.update()

        for evento in pygame.event.get():
            if evento.type == pygame.QUIT: pygame.quit(); sys.exit()
            if evento.type == pygame.KEYDOWN or evento.type == pygame.MOUSEBUTTONDOWN:
                if progreso < total_caracteres: progreso = total_caracteres
                else: esperando = False

def choose_difficulty():
    selecting = True
    rect1 = IMG_BOTON_NOVATO.get_rect(topleft=(ANCHO // 2 - IMG_BOTON_NOVATO.get_width() // 2, 280))
    rect2 = IMG_BOTON_MEDIO.get_rect(topleft=(ANCHO // 2 - IMG_BOTON_MEDIO.get_width() // 2, 370))
    rect3 = IMG_BOTON_DIFICIL.get_rect(topleft=(ANCHO // 2 - IMG_BOTON_DIFICIL.get_width() // 2, 448))

    while selecting:
        dibujar_fondo()
        VENTANA.blit(IMG_MODO_TITULO, (ANCHO // 2 - IMG_MODO_TITULO.get_width() // 2, 130))
        VENTANA.blit(IMG_BOTON_NOVATO, rect1.topleft)
        VENTANA.blit(IMG_BOTON_MEDIO, rect2.topleft)
        VENTANA.blit(IMG_BOTON_DIFICIL, rect3.topleft)
        pygame.display.flip()

        for event in pygame.event.get():
            if event.type == pygame.QUIT: pygame.quit(); sys.exit()
            
            # --- AQUÍ CONFIGURAS VELOCIDAD Y RAPIDEZ ---
            if event.type == pygame.MOUSEBUTTONDOWN:
                if event.button == 1:
                    if rect1.collidepoint(event.pos): return 1, 240 # facil
                    if rect2.collidepoint(event.pos): return 1, 230 # Medio
                    if rect3.collidepoint(event.pos): return 2, 220 # Difícil

def pantalla_inicio():
    corriendo = True
    titulo_surface = render_texto_con_borde("DYNAMIC BEAT", FUENTE_TITULO_GRANDE, NARANJA, NEGRO)
    rect_jugar = IMG_BOTON_JUGAR.get_rect(topleft=(ANCHO//2 - IMG_BOTON_JUGAR.get_width()//2, 320))
    rect_salir = IMG_BOTON_SALIR_INICIO.get_rect(topleft=(ANCHO//2 - IMG_BOTON_SALIR_INICIO.get_width()//2, 440))

    while corriendo:
        dibujar_fondo()
        VENTANA.blit(titulo_surface, (ANCHO//2 - titulo_surface.get_width()//2, 150))
        VENTANA.blit(IMG_BOTON_JUGAR, rect_jugar.topleft)
        VENTANA.blit(IMG_BOTON_SALIR_INICIO, rect_salir.topleft)
        pygame.display.update()

        for evento in pygame.event.get():
            if evento.type == pygame.QUIT: pygame.quit(); sys.exit()
            if evento.type == pygame.MOUSEBUTTONDOWN:
                if evento.button == 1:
                    if rect_jugar.collidepoint(evento.pos): corriendo = False
                    if rect_salir.collidepoint(evento.pos): pygame.quit(); sys.exit()
            if evento.type == pygame.KEYDOWN:
                if evento.key == pygame.K_SPACE: corriendo = False
                if evento.key == pygame.K_ESCAPE: pygame.quit(); sys.exit()

def pantalla_final(aciertos, fallos):
    corriendo = True
    rect_panel = IMG_PANEL_PUNTAJE.get_rect(center=(ANCHO // 2, 310)) # Panel arriba
    rect_reiniciar = IMG_BOTON_REINICIAR.get_rect(center=(ANCHO // 2 - 100, 560)) # Botón izq
    rect_salir = IMG_BOTON_SALIR.get_rect(center=(ANCHO // 2 + 100, 560)) # Botón der
    if aciertos >=1 and aciertos <= 5:
         num_estrellas = 1
    elif aciertos >=6 and aciertos <= 14:
        num_estrellas = 2
    elif aciertos >=15:
        num_estrellas = 3
    else:
        num_estrellas = 0
    while corriendo:
        dibujar_fondo()
        VENTANA.blit(IMG_PANEL_PUNTAJE, rect_panel.topleft)
        #posicion de las estrellas
        pos_estrella_izq = (241, 281)
        pos_estrella_centro = (316, 229)
        pos_estrella_der = (430, 279)

        # Se dibujan según la cantidad ganada
        if num_estrellas >= 1:
            VENTANA.blit(IMG_ESTRELLITA, pos_estrella_izq)
        if num_estrellas >= 2:
            VENTANA.blit(IMG_ESTRELLITA, pos_estrella_der)
        if num_estrellas == 3:
            VENTANA.blit(IMG_ESTRELLA, pos_estrella_centro)
        texto_puntaje = render_texto_con_borde(str(aciertos), FUENTE_PUNTAJE, BLANCO, MARRON)
        VENTANA.blit(texto_puntaje, (420, 410)) 
        VENTANA.blit(IMG_BOTON_REINICIAR, rect_reiniciar.topleft)
        VENTANA.blit(IMG_BOTON_SALIR, rect_salir.topleft)
        
        pygame.display.update()
        
        for evento in pygame.event.get():
            if evento.type == pygame.QUIT: pygame.quit(); sys.exit()
            if evento.type == pygame.MOUSEBUTTONDOWN:
                if evento.button == 1:
                    if rect_reiniciar.collidepoint(evento.pos):
                        main() # Reinicia el juego
                    if rect_salir.collidepoint(evento.pos):
                        pygame.quit(); sys.exit() # Sale del juego

            # Mantenemos las teclas por si acaso
            if evento.type == pygame.KEYDOWN:
                if evento.key == pygame.K_r: main()
                if evento.key == pygame.K_ESCAPE: pygame.quit(); sys.exit()


def main():
    global VELOCIDAD_FLECHA
    pantalla_inicio()
    pantalla_instrucciones()      
    pantalla_instrucciones_2()    
    VELOCIDAD_FLECHA, intervalo = choose_difficulty()
   
    flechas, contador, aciertos, fallos = [], 0, 0, 0
    reloj, muñeco = pygame.time.Clock(), Muñeco()

    flechas, contador, aciertos, fallos = [], 0, 0, 0
    reloj, muñeco = pygame.time.Clock(), Muñeco()
    
    # --- NUEVO: Control de antirrebote ---
    tiempo_ultimo_comando = {'B': 0, 'A': 0, 'C': 0, 'D': 0}
    TIEMPO_COOLDOWN = 400  # Milisegundos que el sistema ignorará esa misma letra
   
    while True:
        reloj.tick(60)
        dibujar_fondo()
        if contador % intervalo == 0 and len(flechas) < TOTAL_RONDAS:
            flechas.append(Flecha(random.choice(DIRECCIONES)))
        contador += 1

        for evento in pygame.event.get():
            if evento.type == pygame.QUIT: pygame.quit(); sys.exit()

        # --- NUEVA LÓGICA DE DETECCIÓN SENSORIAL (CORREGIDA PARA FRASES) ---
        if puerto_serial is not None and puerto_serial.in_waiting > 0:
            try:
                # 1. Leemos la LÍNEA COMPLETA (readline) en lugar de un byte
                linea_entrada = puerto_serial.readline().decode('utf-8').strip().upper()
                tiempo_actual = pygame.time.get_ticks()
                
                # 2. Filtramos: Solo nos importan las líneas que contengan la flecha "->"
                if "->" in linea_entrada:
                    
                    # 3. Cortamos el texto por la flecha y nos quedamos con lo de la derecha ([-1])
                    dato_entrada = linea_entrada.split("->")[-1].strip()
                    
                    if dato_entrada in LETRAS_SERIAL:
                        
                        # Antirrebote
                        if tiempo_actual - tiempo_ultimo_comando[dato_entrada] > TIEMPO_COOLDOWN:
                            tiempo_ultimo_comando[dato_entrada] = tiempo_actual 
                            
                            dir_pres = LETRAS_SERIAL[dato_entrada]
                            acerto = False
                            
                            for f in flechas:
                                if f.activa and f.direccion == dir_pres and abs(f.y - ZONA_ACTIVACION_Y) < ALTURA_ZONA:
                                    aciertos += 1; f.activa = False; muñeco.cambiar_estado("acierto"); acerto = True; break
                            
                            if not acerto: 
                                fallos += 1; muñeco.cambiar_estado("fallo")
                            
                            puerto_serial.reset_input_buffer()
            except Exception as e:
                pass # Evita que el juego se cierre si hay ruido en el puerto serial

        dibujar_zona_activacion()
        VENTANA.blit(img_z1, pos_z1)
        VENTANA.blit(img_z2, pos_z2)
        VENTANA.blit(img_z3, pos_z3)
        VENTANA.blit(img_z4, pos_z4)

        for f in flechas:
            f.mover()
            if f.activa: f.dibujar(VENTANA)
       
        flechas = [f for f in flechas if f.activa]
        muñeco.dibujar(VENTANA)

        # Renderizado del HUD
        texto_stats = render_texto_con_borde(f"Puntos: {aciertos}  Fallos: {fallos}", FUENTE, BLANCO, NEGRO)
        ancho_cuadro_hud = texto_stats.get_width() + 40
        alto_cuadro_hud = texto_stats.get_height() + 20
        cuadro_hud = pygame.transform.scale(FONDO_CUADRO_BASE, (ancho_cuadro_hud, alto_cuadro_hud))
       
        VENTANA.blit(cuadro_hud, (10, 10))
        VENTANA.blit(texto_stats, (30, 20))
       
        pygame.display.update()
        if aciertos + fallos >= TOTAL_RONDAS:
            pygame.time.wait(1000); pantalla_final(aciertos, fallos)

main()

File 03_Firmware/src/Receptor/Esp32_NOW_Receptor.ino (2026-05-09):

#include "ESP32_NOW.h"
#include "WiFi.h"
#include <vector>
#include <string.h>

#define CHANNEL 6

// ================= LED RGB (ANODO COMUN) =================
const int pinRojo = 4;
const int pinVerde = 15;
const int pinAzul = 2;

// ================= MENSAJE =================
typedef struct {
  uint8_t id;
  char estado[20];
} mensaje_t;

mensaje_t mensaje;

// ================= ANTI-REBOTE =================
unsigned long ultimoTiempo[5] = {0};
const unsigned long TIEMPO_REBOTE = 500;

// ================= MAPEO =================
char obtenerLetra(uint8_t id) {
  switch (id) {
    case 1: return 'A';
    case 2: return 'B';
    case 3: return 'C';
    case 4: return 'D';
    default: return '?';
  }
}

const char* obtenerColor(uint8_t id) {
  switch (id) {
    case 1: return "AZUL";
    case 2: return "VERDE";
    case 3: return "ROJO";
    case 4: return "AMARILLO";
    default: return "DESCONOCIDO";
  }
}

// ================= CONTROL RGB =================
void setColor(uint8_t id) {
  // Apagar todos primero
  digitalWrite(pinRojo, HIGH);
  digitalWrite(pinVerde, HIGH);
  digitalWrite(pinAzul, HIGH);

  switch (id) {
    case 1: // AZUL
      digitalWrite(pinAzul, LOW);
      break;

    case 2: // VERDE
      digitalWrite(pinVerde, LOW);
      break;

    case 3: // ROJO
      digitalWrite(pinRojo, LOW);
      break;

    case 4: // AMARILLO (rojo + verde)
      digitalWrite(pinRojo, LOW);
      digitalWrite(pinVerde, LOW);
      break;
  }
}

// ================= ESP-NOW =================
class ReceiverPeer : public ESP_NOW_Peer {
public:
  ReceiverPeer(const uint8_t *mac_addr)
  : ESP_NOW_Peer(mac_addr, CHANNEL, WIFI_IF_STA, nullptr) {}

  bool begin() {
    return add();
  }

  void onReceive(const uint8_t *data, size_t len, bool broadcast) override {

    memcpy(&mensaje, data, sizeof(mensaje));

    if (strcmp(mensaje.estado, "mano detectado") != 0) return;

    unsigned long ahora = millis();

    if (mensaje.id < 1 || mensaje.id > 4) return;

    if (ahora - ultimoTiempo[mensaje.id] < TIEMPO_REBOTE) {
      return;
    }

    ultimoTiempo[mensaje.id] = ahora;

    // ===== ACCION RGB =====
    setColor(mensaje.id);

    // ===== SERIAL =====
    char letra = obtenerLetra(mensaje.id);
    const char* color = obtenerColor(mensaje.id);

    Serial.print("Nodo ");
    Serial.print(mensaje.id);
    Serial.print(" (");
    Serial.print(color);
    Serial.print(") -> ");
    Serial.println(letra);
  }
};

// ================= REGISTRO DINÁMICO =================
std::vector<ReceiverPeer*> peers;

void register_new_peer(const esp_now_recv_info_t *info, const uint8_t *data, int len, void *arg) {
  if (memcmp(info->des_addr, ESP_NOW.BROADCAST_ADDR, 6) == 0) {

    ReceiverPeer *newPeer = new ReceiverPeer(info->src_addr);

    if (newPeer->begin()) {
      peers.push_back(newPeer);
      Serial.println("Nuevo nodo registrado");
    } else {
      Serial.println("Error registrando nodo");
      delete newPeer;
    }
  }
}

// ================= SETUP =================
void setup() {
  Serial.begin(115200);

  // RGB
  pinMode(pinRojo, OUTPUT);
  pinMode(pinVerde, OUTPUT);
  pinMode(pinAzul, OUTPUT);

  // Apagar todo (ánodo común)
  digitalWrite(pinRojo, HIGH);
  digitalWrite(pinVerde, HIGH);
  digitalWrite(pinAzul, HIGH);

  WiFi.mode(WIFI_STA);
  WiFi.disconnect();
  WiFi.setChannel(CHANNEL);

  if (!ESP_NOW.begin()) {
    Serial.println("Error iniciando ESP-NOW");
    while(true);
  }

  ESP_NOW.onNewPeer(register_new_peer, nullptr);

  Serial.println("Receptor listo");
}

// ================= LOOP =================
void loop() {
  delay(200);
}

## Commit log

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2026-02-18 Create README.md
    Se creo la carpeta Dossier y se le dio la descripción.
2026-02-24 Update README.md
    Se edito el archivo README, ahora se indican las primeras librerías usadas en el proyecto, no se subieron archivos, ya que estas librerías están por defecto en el programa de Arduino.
2026-02-24 Create README.md
    Se creo La carpeta Receptor, donde se subirá el código del esp32 encargado de recibir las señales de los esp32 emisores, mediante el protocolo ESP32_NOW, se creo el archivo README, donde se explica e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
2026-02-24 git commit -m "[FIRMWARE] Implementación de comunicación inalámbrica ESP-NOW Closes #4"
    Se subio el Archivo .ino del ESP32 Receptor
2026-02-24 Cambios en el Dossier
    Lean la información presentada en el PDF y verifiquen que todo esté bien.
2026-02-24 [HARDWARE] Consolidación de la BOM Final y Gestión de Proveedores Closes #3
    Se agrega PDF del Bom; Lista de materiales y costos.
2026-02-24 [HARDWARE] Consolidación de la BOM Final y Gestión de Proveedores Closes #3
    Esquemático provisional de conexión fuente-esp, mientras se define que programa se elige para el esquemático final.
2026-02-28 Update README.md
    Se Actualizó el archivo README, con información más clara y detallada.
2026-02-28 Update README.md
    Se puso un espacio para que el archivo readme se vea mucho mejor
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2026-03-18 Create README.md
    Se estructuró el plan de trabajo del proyecto dividiéndolo en cuatro fases principales para el desarrollo del dispositivo. En la primera fase, se elaboró la lista de materiales, se adquirieron los co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
    Posteriormente, la tercera fase abarcó el ensamble de todas las partes y las pruebas de funcionamiento del conjunto. Por último, la cuarta fase se asignó a la ev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
2026-03-18 Datasheet esp32-C3
    Se subió el datasheet del esp32-C3, donde se encuentran el pinout y diferentes especificaciónes.
2026-04-08 Datasheet HCSR04
    Se agregó el datasheet del módulo ultrasónico, el cual contiene las especificaciones técnicas del dispositivo. La información fue tomada de: https://cdn.sparkfun.com/datasheets/Sensors/Proximity/HCSR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
2026-04-08 Revisión y solución de errores en código fuente
    La compañera Leidis trabajo en los cambios dentro del código fuente para modificar significativamente la interfaz del video juego.
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2026-04-08 Add files via upload
    git add 02_Hardware/Datasheets/esp32-C3_SuperMini_datasheet_en.pdf
    git commit -m "ESP32-C3 SuperMini datasheet"
    git push
2026-04-08 Add ESP32-C3 datasheet
    Intento de arreglo de bug
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2026-04-08 Update ESP32-C3 datasheet file name
    se arreglo el nombre
2026-04-08 Subiendo datasheet del ESP32-C3 SuperMini
    Se agrega el PDF con el pinout y especificaciones de voltaje del módulo para el proyecto Dynamic Beat.
2026-04-12 Revisar el archivo README para obtener información sobre la evidencia y la estructura del proyecto.
    Se ha actualizado el archivo README para reflejar la documentación y la organización del proyecto.
2026-04-12 Implementar la medición de distancia y la visualización
    Se agregó la funcionalidad de medición y visualización de distancia mediante la biblioteca U8g2. Se actualizó la estructura de mensajes para incluir la detección de obstáculos.
2026-04-12 Implementar detección de obstáculos e indicación LED
    Se ha añadido funcionalidad de detección de obstáculos y gestión de estados.
2026-04-12 manual técnico y datasheet del módulo L298N
    Contexto:
    Se anexa el documento técnico oficial del módulo controlador de motores L298N al repositorio.
    Detalles:
    El archivo contiene la información de las especificaciones eléctricas, el uso de las borneras de conexión y la configuración del jumper para el regulador de 5V integrado.
    Este documento servirá como referencia directa para la etapa de caracterización del motor DC y para el correcto cableado de la etapa de potencia en la integración final del hardware.
2026-04-12 Actualización de README con arquitectura de hardware para Dynamic Beat
    Se añadió el diagrama de bloques usando sintaxis Mermaid para representar la jerarquía del sistema: gestión de energía (7.4V a 5V), nodos periféricos con sensores HC-SR04 y comunicación ESP-NOW hacia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
2026-04-12 cambio de codigo
    se elimino una parte de un código que no era relevante para la grafica
2026-04-13 agregar componente
    se añadió a la lista de componentes un esp32 que hacia falta
2026-04-15 Matriz de Enfoque Definitiva para Dynamic Beat
    Para cumplir con los estándares de CDIO 3 y la metodología MAHD, he consolidado la matriz utilizando una escala de impacto exponencial (1, 3, 9). Esta escala es preferible en ingeniería porque resalt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
2026-04-22 Evidencias de Interfaz Gráfica de Usuario (GUI)
    Se ha desarrollado e integrado la Interfaz Gráfica de Usuario (GUI) diseñada para centralizar la visualización de datos del sistema.
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2026-05-04 Se agregan archivos del proyecto (código, assets y documentación)
    Se agregaron todos los archivos complementarios requeridos para el correcto funcionamiento del código principal, tales como imágenes, fondos y fuentes tipográficas, cumpliendo con las normas de derechos de autor y licencias de copyright.
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2026-05-04 bom_sourcing
    Actualizar de la lista de materiales del bom_sourcing.
    [BOM_Sourcing.xlsx]
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2026-05-04 Carlos branch01 (#46)
    * bom_sourcing
    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
    [BOM_Sourcing.xlsx]
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2026-05-04 Actualización de ramas. (#48)
    * Merge pull request #40 from javiersocampoy-sys/main (#41)
    * Actualización de ramas. (#43) (#44)
    Added audit evidence details and i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
    [BOM_Sourcing.xlsx]
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2026-05-06 Delete 02_Hardware/Datasheets/BOM_Sourcing.xlsx
    Se elimino un archivo corrupto
    [BOM_Sourcing.xlsx]
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2026-05-19 Leidis branch01 (#68)
    * Carga de archivos 3D de las carcasas
    Estos son los archivos 3D de las cajas de los sensores.
    * Se añadió el archivo 3D de la caja maestro.
    Se cargaran 2 tipos de archivos diferentes del mismo modelo 3D para mayor compatibilidad entre programas 3D.
    [Caja CDIO Maestro.stl, Caja CDIO.stl]
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
